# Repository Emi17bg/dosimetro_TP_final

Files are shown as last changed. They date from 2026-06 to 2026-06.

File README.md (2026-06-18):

# Prototipo de bomba de infusión volumétrica automatizada con PIC16F887
Asignatura: Electrónica Digital II - Universidad Nacional de Córdoba 
Integrantes: Bagnera, Maria Emilia - Bauchwitz, Lautaro - Faimberg, Mijal
Profesor: Marcos Blasco

## 1. Descripción general del proyecto

El proyecto consiste en el desarrollo de una bomba de infusión automatizada controlado por un microcontrolador PIC16F887. El sistema permite accionar un motor paso a paso encargado de desplazar el émbolo de una jeringa, con el objetivo de dispensar un volumen de manera controlada. La cantidad de pasos o dosis puede ser ingresada desde una computadora mediante comunicación serie UART, mientras que el sistema muestra información en dos displays de 7 segmentos multiplexados.

---

## 2. Alcances del proyecto

### El sistema sí es capaz de:

* Controlar un motor paso a paso mediante un driver externo.
* Generar señales STEP y DIR desde el PIC16F887.
* Recibir datos desde una computadora mediante comunicación UART.
* Guardar el valor recibido en una variable interna del programa.
* Mostrar datos en dos displays de 7 segmentos.
* Multiplexar los displays utilizando interrupción por Timer0.
* Leer una señal analógica mediante el ADC interno del PIC.
* Utilizar un potenciómetro como entrada analógica para estimar posición o volumen.
* Detectar un pulsador externo conectado a RB0.
* Ejecutar una acción de recarga o movimiento a partir de una interrupción externa.
* Trabajar con alimentación lógica de 5 V y alimentación independiente para el motor.

### El sistema no incluye:

* Certificación médica para uso clínico real.
* Control cerrado de volumen con sensor calibrado de alta precisión.
* Almacenamiento de datos en tarjeta SD o memoria externa.
* Interfaz gráfica en computadora.
* Sistema de batería o bajo consumo.
* Sensores de presión, finales de carrera o detección automática de obstrucciones.
* Validación metrológica completa del volumen dispensado.

---

## 3. Posibles etapas siguientes

En una versión futura del sistema se podrían implementar las siguientes mejoras:

* Diseñar una placa PCB para reemplazar el montaje en protoboard.
* Agregar finales de carrera para detectar posición inicial y final del mecanismo.
* Calibrar la relación entre pasos del motor y volumen desplazado.
* Incorporar una interfaz gráfica en Python para ingresar dosis y visualizar el estado del sistema.
* Agregar registro de datos para almacenar dosis aplicadas.
* Incorporar una pantalla LCD u OLED para mejorar la visualización local.
* Implementar detección de errores ante trabas mecánicas o desconexión del motor.
* Diseñar una carcasa mecánica para fijar la jeringa, el motor y el sistema de transmisión.
* Mejorar el filtrado de la señal analógica del potenciómetro.

---

# 4. Arquitectura del sistema

## Hardware utilizado

El sistema está compuesto por los siguientes bloques:

* Microcontrolador PIC16F887.
* Cristal externo de 4 MHz.
* Driver A4988 para motor paso a paso.
* Motor paso a paso tipo NEMA 17.
* Jeringa acoplada mecánicamente al motor.
* Potenciómetro conectado a una entrada analógica.
* Dos displays de 7 segmentos cátodo común.
* Transistores para habilitar cada display en el multiplexado.
* Pulsador externo conectado a RB0.
* Comunicación UART con computadora.
* Fuente de 12 V para el motor.
* Regulador o módulo step-down de 5 V para la lógica digital.

## Esquemático del circuito

El siguiente esquemático muestra la conexión general entre el PIC16F887 y los módulos principales del sistema: alimentación, entrada analógica, comunicación UART, displays de 7 segmentos, pulsador externo y driver del motor paso a paso.

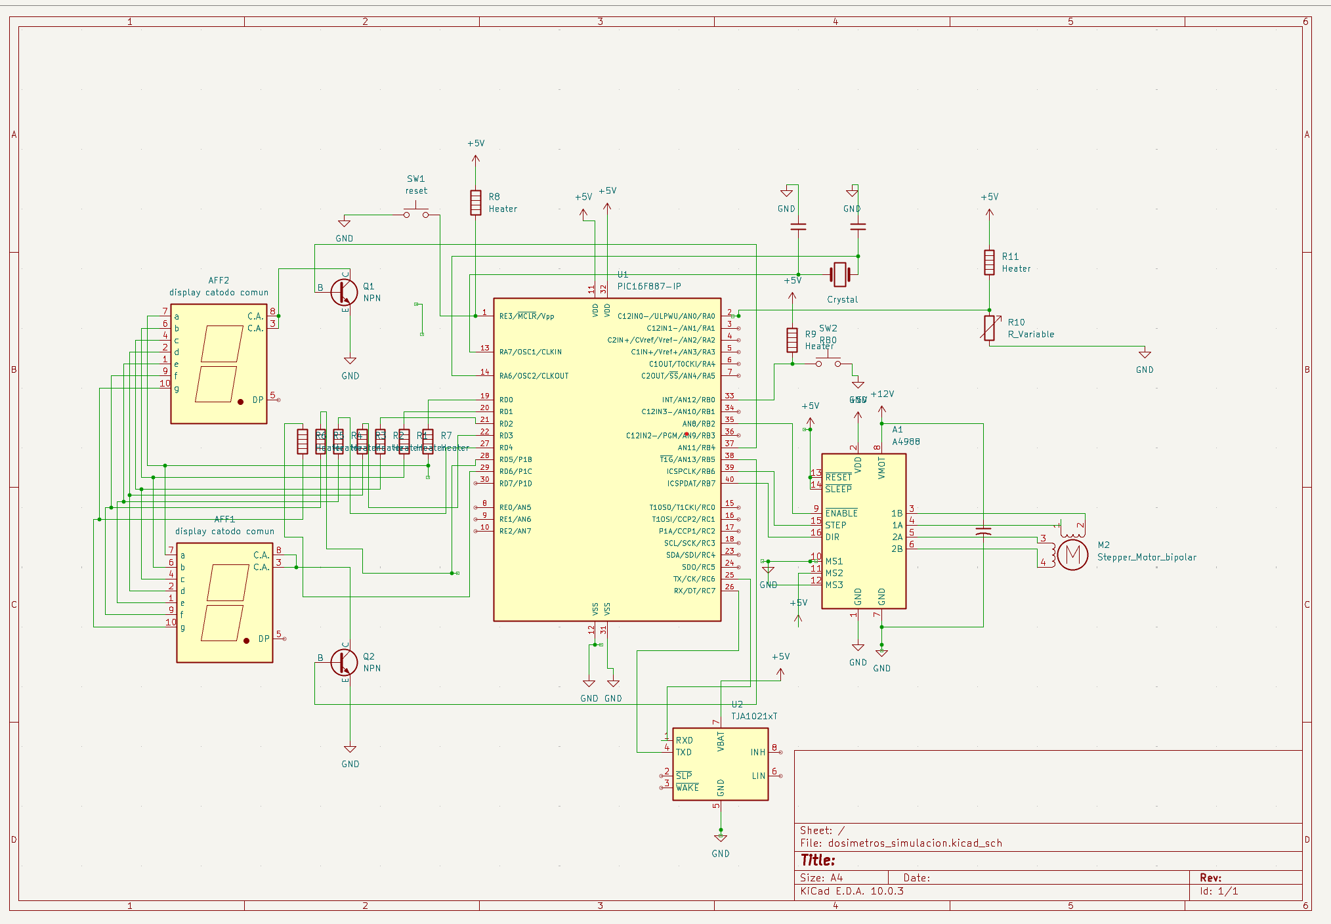
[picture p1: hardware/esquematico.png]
Esquemático completo


## Prototipo físico

La siguiente imagen muestra el montaje físico del sistema desarrollado, incluyendo el microcontrolador, la etapa de potencia, los elementos de visualización y el mecanismo asociado al accionamiento de la jeringa.

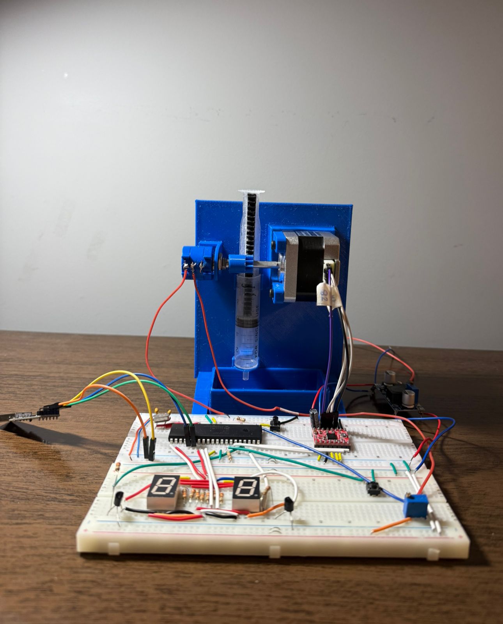
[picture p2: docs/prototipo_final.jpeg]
Prototipo físico


---

# 5. Descripción del circuito

El PIC16F887 funciona como unidad central de control. El microcontrolador recibe información desde una computadora mediante UART, lee una entrada analógica proveniente de un potenciómetro y genera señales digitales para controlar el driver del motor paso a paso. También controla dos displays de 7 segmentos mediante multiplexado.

Los segmentos de los displays se conectan al puerto D del PIC. La selección de cada display se realiza mediante transistores controlados desde pines del puerto B. El multiplexado se realiza alternando rápidamente la habilitación de cada display mediante interrupciones del Timer0, de manera que el usuario perciba ambos displays encendidos al mismo tiempo.

El motor paso a paso se controla mediante un driver externo. El PIC entrega las señales STEP y DIR, mientras que el driver se encarga de alimentar las bobinas del motor. La fuente de potencia del motor es independiente de la alimentación lógica del PIC, pero ambas deben compartir GND para que las señales de control tengan una referencia común.

El potenciómetro se conecta como divisor resistivo entre 5 V y GND. El terminal central del potenciómetro se conecta a una entrada analógica del PIC, por ejemplo AN0. Esta tensión es convertida por el módulo ADC y puede utilizarse para estimar posición del mecanismo o volumen restante.

---

# 6. Conexiones principales

## Alimentación

| Elemento | Conexión |
| --- | --- |
| PIC16F887 | 5 V |
| Driver del motor | 12 V para potencia |
| Lógica del driver | 5 V |
| GND del PIC | GND común |
| GND de la fuente de 12 V | GND común |

## Microcontrolador PIC16F887

| Pin / Puerto | Función |
| --- | --- |
| RA0 / AN0 | Entrada analógica del potenciómetro |
| RB0 | Pulsador externo |
| RB4 | Habilitación display 1 |
| RB5 | Habilitación display 2 |
| RB6 | Señal STEP hacia el driver |
| RB7 | Señal DIR hacia el driver |
| RC6 / TX | Transmisión UART |
| RC7 / RX | Recepción UART |
| RD0 a RD7 | Segmentos de los displays |
| OSC1 / OSC2  | Cristal externo de 4 MHz |
| MCLR | Reset externo del PIC |

---

# 7. Arquitectura de software

## Herramientas utilizadas

* MPLAB X IDE v5.35.
* Ensamblador para PIC.
* Lenguaje Assembly.
* Microcontrolador PIC16F887.
* Bootloader AN1310 o programador compatible.
* Terminal serie para envío de datos desde la computadora.

## Periféricos internos utilizados

* Timer0 para multiplexado de displays.
* ADC para lectura del potenciómetro.
* EUSART/UART para comunicación serie.
* Interrupción externa por RB0.
* Puertos digitales para displays y control del motor.

## Configuración general

El sistema utiliza un cristal externo de 4 MHz. El Watchdog Timer se encuentra desactivado para evitar reinicios no deseados durante las pruebas. El pin MCLR se mantiene habilitado como reset externo. El módulo ADC se configura para leer el canal AN0. La comunicación UART se configura para recibir datos enviados desde una terminal serie en la computadora.

## Diagrama de flujo del firmware
El siguiente diagrama representa el flujo general del firmware implementado en el PIC16F887. Se muestra la inicialización de periféricos, el lazo principal y el orden de atención de interrupciones utilizado en el sistema.

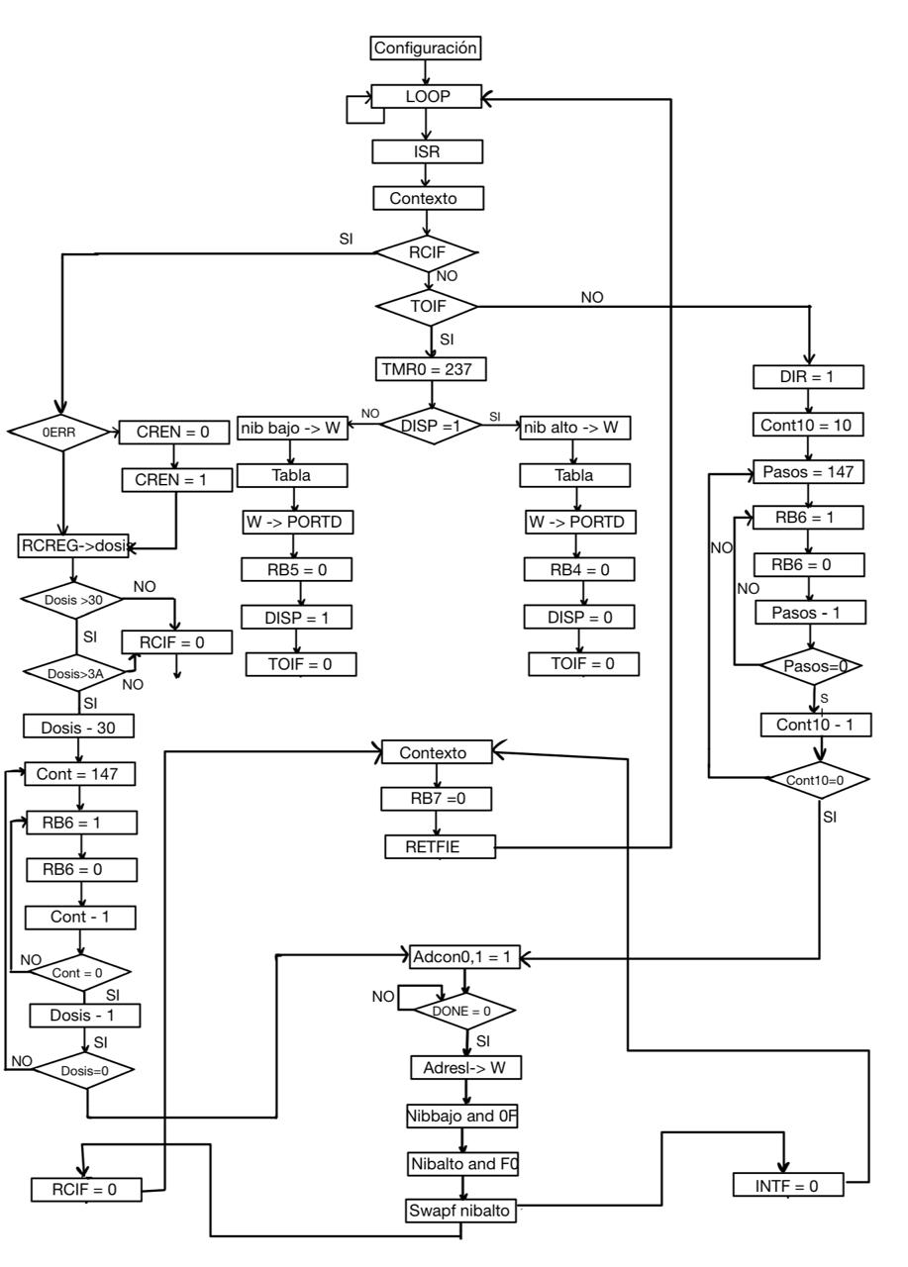
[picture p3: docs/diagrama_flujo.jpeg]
Diagrama de flujo del firmware


---

# 8. Fuses o bits de configuración

Configuración utilizada:

```asm
__CONFIG _CONFIG1, _FOSC_XT & _WDTE_OFF & _PWRTE_ON & _MCLRE_ON & _CP_OFF & _BOREN_OFF & _IESO_OFF & _FCMEN_OFF & _LVP_OFF
__CONFIG _CONFIG2, _WRT_OFF & _BOR4V_BOR40V
```

Descripción:

| Parámetro | Configuración |
| --- | --- |
| Oscilador | XT, cristal externo |
| Frecuencia | 4 MHz |
| Watchdog Timer | Desactivado |
| Power-up Timer | Activado |
| MCLR | Activado como pin externo |
| Code Protection | Desactivado |
| Brown-out Reset | Desactivado |
| Low Voltage Programming | Desactivado |
| Fail-Safe Clock Monitor | Desactivado |
| Internal/External Switchover | Desactivado |

---

# 9. Gestión de interrupciones

El PIC16F887 posee un único vector de interrupción en la dirección 0x04. Por este motivo, dentro de la rutina de interrupción se debe consultar qué bandera generó el evento.

El orden de atención utilizado o propuesto es:

1. UART: se atiende primero para guardar el dato recibido desde la computadora y evitar pérdida de información. Esta prioridad permite que el sistema no pierda caracteres enviados desde el teclado.
2. RB0: se atiende luego para detectar el pulsador externo, utilizado para iniciar una acción manual del sistema, como recarga o movimiento.
3. Timer0: se atiende después para mantener el multiplexado de los displays de 7 segmentos.
4. ADC: si se utiliza para la conversión, se atiende luego de las tareas principales.

Este criterio permite mantener estable la visualización y atender correctamente la comunicación serie y las entradas externas.

---

# 10. Funcionamiento general del firmware

El programa comienza configurando los puertos del microcontrolador, los registros de interrupción, el Timer0, el ADC y la UART. Luego entra en un lazo principal infinito donde el sistema queda esperando eventos.

Cuando se recibe un dato por UART, el valor se guarda en una variable interna. Ese dato puede ser utilizado para definir la cantidad de pasos del motor o para actualizar la visualización en los displays. Cuando se genera una interrupción por Timer0, el firmware alterna entre los dos displays para lograr el multiplexado.

Cuando se presiona el pulsador conectado a RB0, el sistema ejecuta una acción definida, como iniciar una recarga completa o mover el motor una cantidad determinada de pasos. La lectura del potenciómetro mediante ADC permite obtener una referencia analógica asociada a la posición del sistema.

---
# 12. Ensayos y pruebas realizadas

Prueba de alimentación

Se midió la tensión de alimentación del PIC y del driver del motor. Se verificó la presencia de 5 V para la lógica y 12 V para la etapa de potencia. También se comprobó que ambas fuentes compartieran GND.

Evidencia:

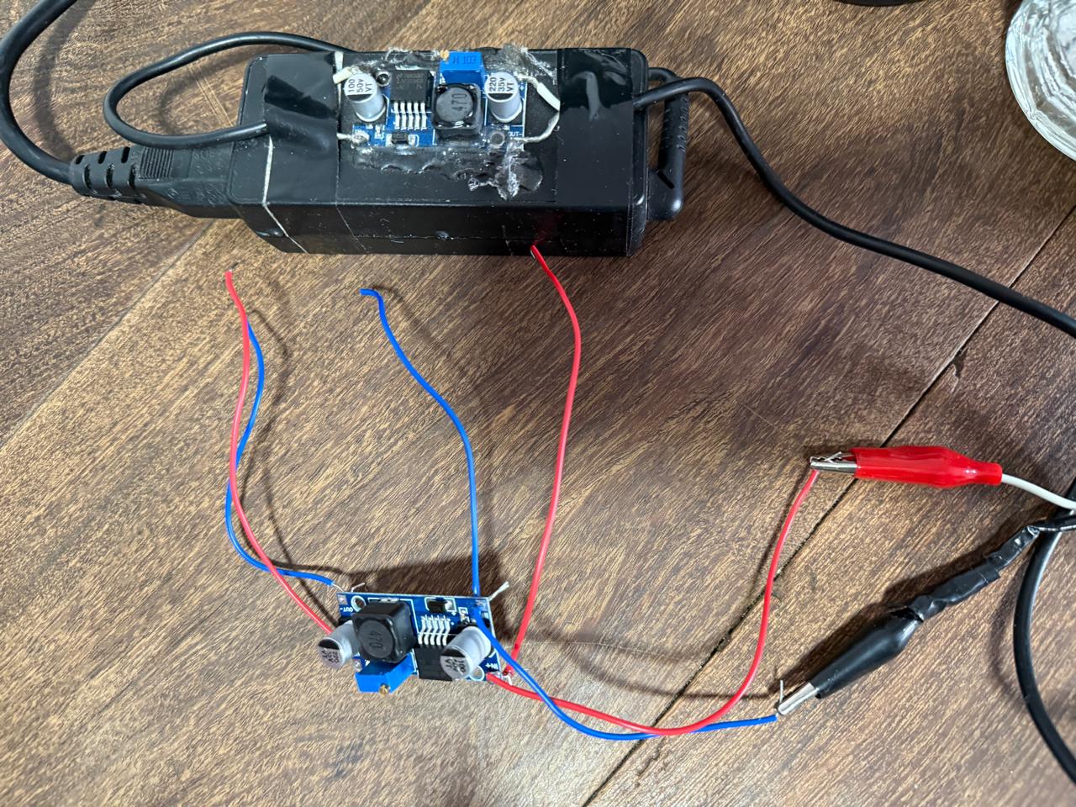
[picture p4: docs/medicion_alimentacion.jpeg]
Medición de alimentación


Prueba de displays

Se cargaron valores de prueba en las variables internas y se comprobó la correcta visualización en los dos displays de 7 segmentos. También se verificó que el multiplexado no produjera parpadeo visible.

Evidencia:

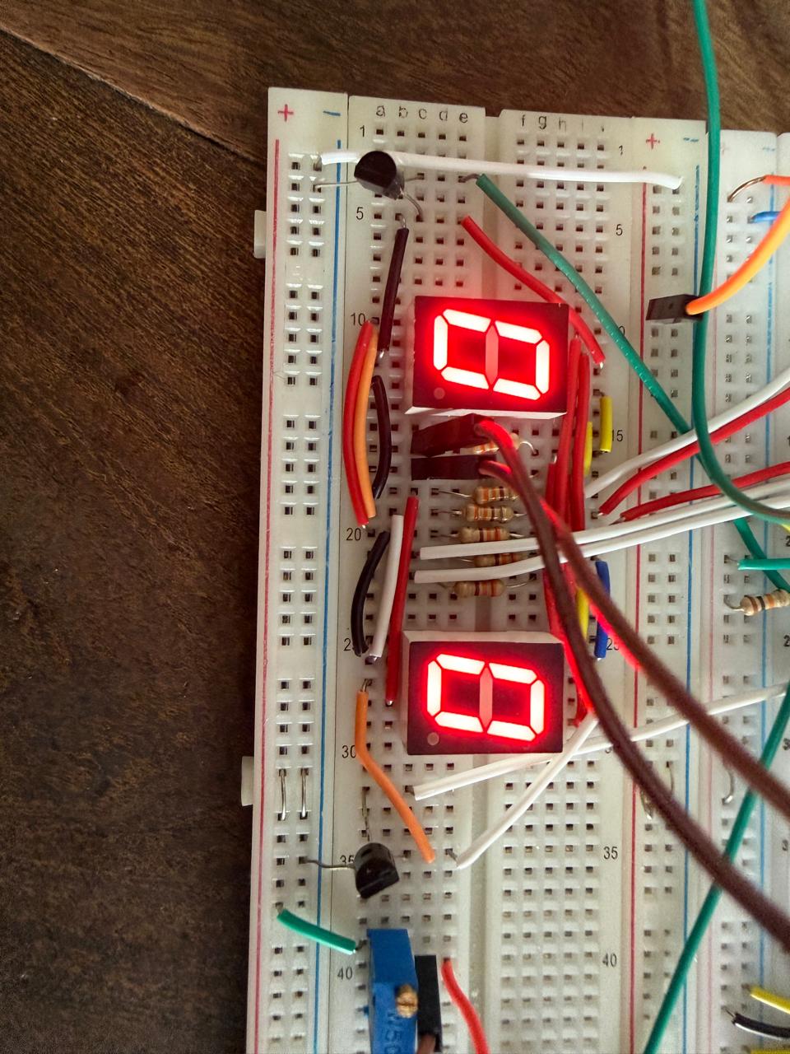
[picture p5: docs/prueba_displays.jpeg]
Prueba de displays

Prueba de comunicación UART

Se enviaron caracteres numéricos desde una terminal serie en la computadora. El PIC recibió los datos mediante el módulo EUSART y los almacenó en una variable interna.

Evidencia:

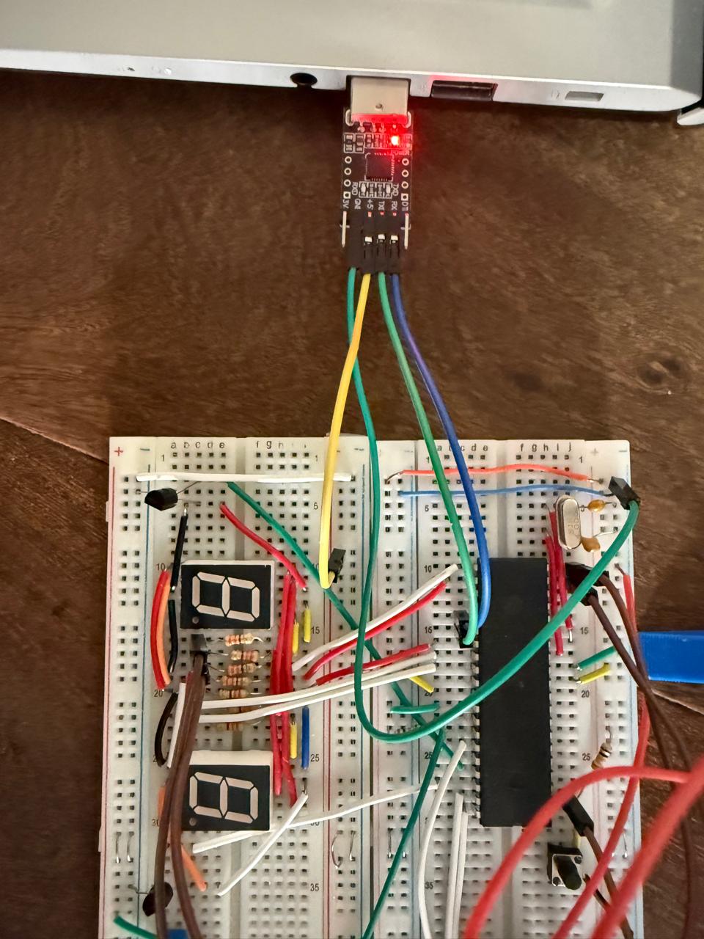
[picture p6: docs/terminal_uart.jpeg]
Terminal UART

Prueba del ADC

Se varió la posición del potenciómetro conectado a AN0 y se verificó el cambio en el valor convertido por el ADC. Esta prueba permitió comprobar que el microcontrolador detecta correctamente variaciones analógicas.

Evidencia:

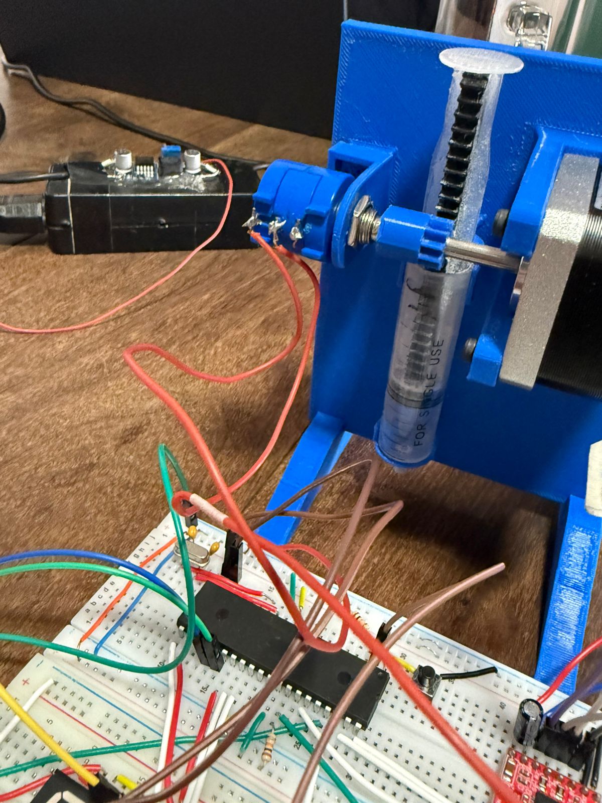
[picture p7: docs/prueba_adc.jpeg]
Prueba ADC

Prueba del motor

Se enviaron pulsos STEP al driver del motor paso a paso y se verificó el movimiento del eje. También se probó la señal DIR para modificar el sentido de giro.

Evidencia:

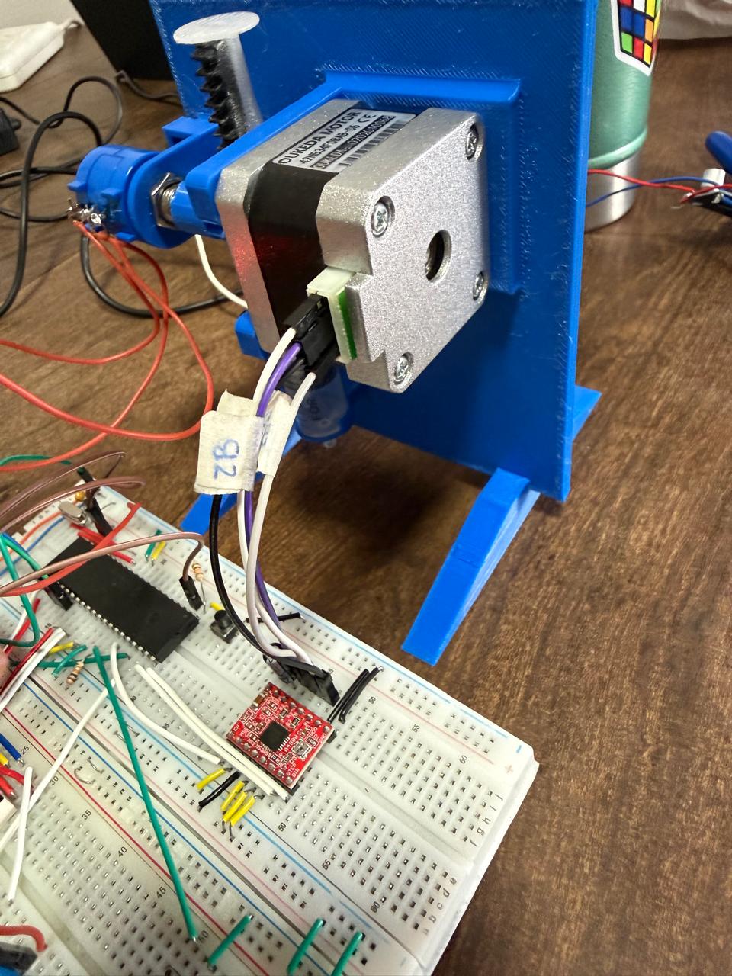
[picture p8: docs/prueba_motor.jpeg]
Prueba motor


---

# 13. Resultados obtenidos

El prototipo permitió validar el funcionamiento básico de un dosímetro volumétrico automatizado. Se logró controlar el motor paso a paso mediante el PIC16F887, visualizar información en displays de 7 segmentos, recibir datos desde una computadora por UART y leer una señal analógica mediante el ADC.

Los resultados obtenidos demuestran que el sistema cumple con los objetivos principales planteados para la entrega final. Sin embargo, para una aplicación profesional sería necesario mejorar la calibración del volumen, incorporar sensores de seguridad, diseñar una PCB, realizar mediciones de repetibilidad y validar el sistema bajo condiciones controladas.

---

# 14. Estructura sugerida del repositorio

```text
dosimetro-pic16f887/
│
├── README.md
│
├── firmware/
│   └── main.asm
│
├── hardware/
│   ├── esquematico.png
│   └── dosimetros_simulacion
│
├── docs/
    ├── diagrama_bloques.png
    ├── diagrama_software.png
    ├── medicion_alimentacion.png
    ├── prueba_displays.png
    ├── terminal_uart.png
    ├── prueba_adc.png
    ├── prueba_motor.png
    └── prototipo_final.png

```

---

# 15. Conclusión

El proyecto permitió integrar distintos contenidos de electrónica digital y sistemas embebidos, incluyendo programación en Assembly, manejo de interrupciones, comunicación UART, conversión analógica-digital, multiplexado de displays y control de motores paso a paso.

El sistema desarrollado constituye una base funcional para un dosificador volumétrico automatizado. Aunque el prototipo no está diseñado para uso clínico real, permite demostrar el principio de funcionamiento y deja planteadas mejoras futuras relacionadas con seguridad, precisión, calibración y robustez del diseño.

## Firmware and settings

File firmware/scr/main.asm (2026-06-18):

LIST P=16F887
RADIX DEC
#include "p16f887.inc"

;--------------------------------------------------------
; CONFIG
;--------------------------------------------------------
__CONFIG _CONFIG1, _FOSC_XT & _WDTE_OFF & _PWRTE_ON & _MCLRE_ON & _CP_OFF & _BOREN_OFF & _IESO_OFF & _FCMEN_OFF & _LVP_OFF
__CONFIG _CONFIG2, _WRT_OFF & _BOR4V_BOR40V


PASOS   	EQU 0x70
W_TEMP  	EQU 0x71
STATUS_TEMP EQU 0x72
D1      	EQU 0x73
D2      	EQU 0x74
DISP    	EQU 0x75
NIB_BAJO	EQU 0x76
NIB_ALTO	EQU 0x77
DOSIS   	EQU 0x78
PASOS_H     EQU 0X79
contador147 EQU 0x7A
DECENAS     EQU 0x7C
UNIDADES    EQU 0x7D
contador10  EQU 0x7B
 
ORG 0x00
GOTO INICIO
 
ORG 0x04
GOTO ISR
 
INICIO  
 
;BANCO 0
CLRF PORTD
CLRF PORTB
CLRF PORTC
CLRF PASOS
CLRF PASOS_H
CLRF DISP
CLRF DOSIS
CLRF contador147
CLRF contador10
CLRF DECENAS
CLRF UNIDADES
MOVLW B'10000001'
MOVWF ADCON0
MOVLW B'10010000'
MOVWF RCSTA
    
;BANCO 1    
BSF STATUS, RP0
MOVLW B'00000001'
MOVWF TRISB   
MOVLW B'10000111'
MOVWF OPTION_REG
CLRF TRISD
MOVLW B'10000000'
MOVWF ADCON1
MOVLW B'10000000'
MOVWF TRISC
MOVLW B'00100100'
MOVWF TXSTA
MOVLW .25
MOVWF SPBRG
BSF PIE1, RCIE

;BANCO 3
BSF STATUS, RP1
MOVLW B'00000001'
MOVWF ANSEL
CLRF ANSELH
BCF BAUDCTL, BRG16
  	 
;BANCO 0
BCF STATUS, RP0
BCF STATUS, RP1
MOVLW B'11110000'
BCF PIR1, RCIF
MOVWF INTCON
CLRF PORTB
MOVLW .237
MOVWF TMR0
BCF PORTB,7
BCF INTCON, INTF
BCF INTCON, T0IF

LOOP
GOTO LOOP
 
ISR
MOVWF W_TEMP
SWAPF STATUS, W
MOVWF STATUS_TEMP

BTFSC PIR1, RCIF
GOTO PERIF
BTFSC INTCON,T0IF
goto TIMER0
goto PULSADOR


PERIF
BTFSS RCSTA, OERR
GOTO LEER_UART
BCF RCSTA, CREN
BSF RCSTA, CREN

LEER_UART
MOVF RCREG, W
MOVWF DOSIS
MOVLW 0x30
SUBWF DOSIS, W
BTFSS STATUS, C
GOTO FIN_PERIF
MOVLW 0X3A
SUBWF DOSIS, W
BTFSC STATUS, C
GOTO FIN_PERIF
MOVLW 0X30
SUBWF DOSIS, F

; DOSIS ya vale de 0 a 9

MOVF DOSIS, W

   	; byte alto

CALL MOVER_PASOS

CALL ACTUALIZAR_ADC
GOTO FIN_PERIF


MOVER_PASOS
    MOVLW   .147
    MOVWF   contador147

BUCLE_147
    CALL    DAR_PASO
    DECFSZ  contador147, F
    GOTO    BUCLE_147

    DECFSZ  DOSIS, F
    GOTO    MOVER_PASOS

    RETURN


 
DAR_PASO
BSF 	PORTB, 6     	 
CALL	DELAY_STEP
BCF 	PORTB, 6     	 
CALL	DELAY_STEP
RETURN

DELAY_STEP
MOVLW   D'40'
MOVWF   D1
DLY1
MOVLW   D'200'
MOVWF   D2
DLY2
DECFSZ  D2, F
GOTO	DLY2
DECFSZ  D1, F
GOTO	DLY1
RETURN
  	 
FIN_PERIF
BCF PIR1, RCIF
GOTO FIN_ISR
	 
ACTUALIZAR_ADC
CALL DELAY_STEP
BSF ADCON0, 1
CALL DELAY_ADC
BSF STATUS, RP0
MOVF ADRESL, W
;ANDLW 0x0F
BCF STATUS, RP0
CALL CONVERTIR_DECIMAL
;MOVWF NIB_BAJO
;MOVF ADRESL, W
;ANDLW 0xF0
;MOVWF NIB_ALTO
;SWAPF NIB_ALTO, F
;BCF STATUS, RP0
RETURN

CONVERTIR_DECIMAL
    MOVWF UNIDADES
    CLRF DECENAS
RESTAR_10
    MOVLW D'10'
    SUBWF UNIDADES,W
    BTFSS STATUS,C ;Si unidades - 10 es negativo, C es 0, salgo del bucle
    GOTO CONV_FIN
    MOVWF UNIDADES
    INCF DECENAS,F
    GOTO RESTAR_10
CONV_FIN
    return
DELAY_ADC
BTFSC   ADCON0, 1
GOTO	DELAY_ADC
RETURN
  	 

TIMER0
MOVLW .237
MOVWF TMR0
CLRF PORTD
BCF PORTB, 4
BCF PORTB, 5

BTFSS DISP, 0
GOTO PRIMERO
GOTO SEGUNDO

SEGUNDO
MOVF DECENAS, W
CALL TABLA
MOVWF PORTD
BSF PORTB,4
BCF DISP, 0
BCF INTCON, T0IF
GOTO FIN_ISR

PRIMERO
MOVF UNIDADES, W
CALL TABLA
MOVWF PORTD
BSF PORTB,5
BSF DISP, 0
BCF INTCON, T0IF
GOTO FIN_ISR

    
PULSADOR
BSF PORTB,7
movlw .10
movwf contador10
BUCLEREPETIR10
CALL MOVER1ML
DECFSZ contador10
goto BUCLEREPETIR10

CALL ACTUALIZAR_ADC
BCF INTCON, INTF
GOTO FIN_ISR

MOVER1ML
MOVLW .147
MOVWF PASOS
BUCLE_20

    	CALL	DAR_PASO

    	DECFSZ  PASOS, F
    	GOTO	BUCLE_20
RETURN

FIN_ISR
BCF PORTB,7
SWAPF STATUS_TEMP, W
MOVWF STATUS
SWAPF W_TEMP, F
SWAPF W_TEMP, W
RETFIE

TABLA
   ADDWF   PCL, F

    	RETLW   B'00111111'   	; 0
    	RETLW   B'00000110'   	; 1
    	RETLW   B'01011011'   	; 2
    	RETLW   B'01001111'   	; 3
    	RETLW   B'01100110'   	; 4
    	RETLW   B'01101101'   	; 5
    	RETLW   B'01111101'   	; 6
    	RETLW   B'00000111'   	; 7
    	RETLW   B'01111111'   	; 8
    	RETLW   B'01101111'   	; 9
    	RETLW   B'01110111'   	; A
    	RETLW   B'01111100'   	; b
    	RETLW   B'00111001'   	; C
    	RETLW   B'01011110'   	; d
    	RETLW   B'01111001'   	; E
    	RETLW   B'01110001'   	; F

END

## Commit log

2026-06-17 primer commit
    [dosimetros_simulacion.kicad_pcb, dosimetros_simulacion.kicad_sch]
2026-06-18 Actualizar diagrama de flujo del firmware
2026-06-18 Actualizar diagrama de flujo
